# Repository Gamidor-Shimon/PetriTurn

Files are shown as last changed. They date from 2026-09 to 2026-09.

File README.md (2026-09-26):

# PetriTurn — Gamidor

מכשיר לסיבוב צלחת פטרי בזמן זריעת חיידקים.
הרובוט מחזיק את הלופה, והמכשיר מסובב את הצלחת לפי תוכנית שנשמרה מראש בבקר.

```
Robot → petriturn.exe (Python) → USB → XIAO ESP32-C3 → TMC2209 → NEMA17 → Petri dish
                 ↑
   petriturn_gui (program editor) → writes programs into the controller's flash
```

הפרויקט בנוי משלושה חלקים:

1. **קושחה** לבקר — `firmware/PetriTurn/PetriTurn.ino`
2. **שורת פקודה לרובוט** — `host/petriturn.py` (לאחר בנייה: `petriturn.exe`)
3. **תוכנת ניהול (GUI)** — `host/petriturn_gui.py`, בעיצוב Gamidor

---

## תוכן עניינים

1. [מבנה התיקיות](#מבנה-התיקיות)
2. [חומרה](#חומרה)
3. [התקנה ראשונה](#התקנה-ראשונה)
4. [קובץ ההגדרות petriturn.ini](#קובץ-ההגדרות-petriturnini)
5. [תוכנת הניהול (GUI)](#תוכנת-הניהול-gui)
6. [שורת הפקודה לרובוט](#שורת-הפקודה-לרובוט)
7. [פרוטוקול התקשורת עם הבקר](#פרוטוקול-התקשורת-עם-הבקר)
8. [פתרון תקלות](#פתרון-תקלות)
9. [בניית חבילה ללקוח](#בניית-חבילה-ללקוח)
10. [התקנה אצל הלקוח](#התקנה-אצל-הלקוח)
11. [כללי בטיחות](#כללי-בטיחות)

---

## מבנה התיקיות

```
PetriTurn/
├── README.md                      this document
├── WIRING.md                      pin-by-pin wiring: controller, driver, motor, power
├── Motor_Driver_Design_Notes.md   design notes: motor, driver, decisions, risks
├── PetriTurn.bat                  development only: runs the GUI from source (.venv)
├── build.bat                      builds the installer: PetriTurn\PetriTurn-Setup-<version>.exe
├── installer/                     Inno Setup script + Gamidor wizard images
├── enclosure/                     3D-printed box: FreeCAD script, STL, STEP, previews
├── perfboard/                     controller board: layout + check, README generator, drawings
├── requirements.txt               Python packages
├── firmware/
│   └── PetriTurn/
│       └── PetriTurn.ino       controller firmware
└── host/
    ├── petriturn.ini                settings: port, baud rate, timeouts
    ├── petriturn.py                 robot command line
    ├── petriturn_gui.py             control GUI
    ├── petriturn_link.py            shared code: serial link, programs, settings
    ├── petriturn_log.py             audit log (logs folder, 5 MB parts, never deleted)
    ├── theme.py                   Gamidor design tokens (gamidor-ui-design skill)
    └── assets/                    logo and icon
```

---

## חומרה

הפירוט המלא, רגל אחר רגל, עם שרטוטים ובדיקות: **[WIRING.md](WIRING.md)**.
הקופסה המודפסת (130 × 96, עם פאנל חיבורים), חלקים, הדפסה והרכבה: **[enclosure/README.md](enclosure/README.md)**.
לוח ההלחמה, סידור רכיבים וחיבורים: **[perfboard/README.md](perfboard/README.md)**.

### רכיבים

| רכיב | דגם / ערך |
|---|---|
| בקר | Seeed XIAO ESP32-C3 |
| דרייבר | TMC2209 (לוח V985), חיישת זרם `R110` = 0.11Ω |
| מנוע | LAM M1173040, NEMA17, ‏1.8°, ‏0.7A, ‏9.3Ω לסליל |
| ספק | 24V, לפחות 1.5A |
| קבל | 100µF / 35V אלקטרוליטי |
| נגדים | 1kΩ, ‏10kΩ |

### חיווט בקר ← דרייבר

| XIAO | GPIO | דרייבר TMC2209 | הערה |
|---|---|---|---|
| `3V3` | — | `VDD` (ימין, פין 7) | מתח לוגיקה |
| `GND` | — | `GND` (ימין, פין 8) | אדמה משותפת, חובה |
| `D1` | GPIO3 | `EN` (שמאל, פין 1) | + נגד **10kΩ מ-EN אל 3.3V** — המנוע כבוי בזמן עליית הבקר |
| `D2` | GPIO4 | `STEP` (שמאל, פין 7) | |
| `D3` | GPIO5 | `DIR` (שמאל, פין 8) | |
| `D4` | GPIO6 | `USART` (שמאל, פין 5) | **דרך נגד 1kΩ** |
| `D5` | GPIO7 | `USART` (שמאל, פין 5) | חוט ישיר |
| — | — | `MS1`, `MS2` | אל GND — כתובת דרייבר 0 |
| — | — | `PDN`, `CLK`, `DIAG`, `INDEX`, `VREF` | לא מחוברים |

- פינים `D0`, `D8`, `D9` של ה-XIAO הם פיני אתחול — **לא לחבר אליהם דבר**.
- `D6`/`D7` נשארים פנויים (הבקר מדפיס עליהם הודעות אתחול).
- **חוטים ליד שקע ה-USB-C** עלולים למנוע מהתקע להיכנס עד הסוף, והמחשב לא יזהה את הבקר. להרחיק אותם מהשקע.

### חיווט ספק ומנוע

| מ- | אל | הערה |
|---|---|---|
| ספק 24V (+) | `VM` (ימין, פין 1) | + רגל **+** (הארוכה) של קבל 100µF, צמוד לדרייבר |
| ספק 24V (−) | `GND` (ימין, פין 2) | + רגל **−** (הפס) של הקבל |
| מנוע שחור | `A2` (ימין, פין 3) | |
| מנוע ירוק | `A1` (ימין, פין 4) | |
| מנוע אדום | `B1` (ימין, פין 5) | |
| מנוע כחול | `B2` (ימין, פין 6) | |

בדיקה לפני חיבור המנוע: שחור–ירוק ≈ 9.3Ω, אדום–כחול ≈ 9.3Ω.

**סדר הדלקה:** USB קודם, 24V אחר כך. **כיבוי:** לשחרר את הצלחת, לכבות 24V, ואז USB.
כשאין 24V הדרייבר לא עונה (`DRV=0x00`) — זה תקין.

---

## התקנה ראשונה

### 1. קושחה (Arduino IDE)

1. **Boards Manager:** להתקין `esp32` by Espressif.
2. **Library Manager:** להתקין `TMCStepper` (teemuatlut) ו-`AccelStepper` (Mike McCauley).
3. לפתוח את `firmware/PetriTurn/PetriTurn.ino`.
4. **Tools:**
   - Board: `XIAO_ESP32C3`
   - USB CDC On Boot: **`Enabled`** — בלי זה אין תקשורת דרך ה-USB
   - Port: הפורט של הבקר
5. Upload.

אם הצריבה נכשלת: לנתק USB, להחזיק את כפתור **BOOT**, לחבר USB, לשחרר, ולצרוב שוב.

בדיקה ב-Serial Monitor (115200, סוף שורה `Newline`): לשלוח `STATUS`.
עם 24V מחובר צריך לחזור `DRV=0x21`.

### 2. תוכנה במחשב

צריך Python 3.11 ומעלה. מתיקיית הפרויקט:

```bash
python -m venv .venv
```
```bash
.venv\Scripts\python -m pip install -r requirements.txt
```

הסביבה `.venv` נשמרת בתוך תיקיית הפרויקט. ב-Python שמותקן מ-Microsoft Store,
התקנת PySide6 מחוץ לסביבה כזו נכשלת בגלל נתיבים ארוכים מדי.

### 3. הפעלה

- **GUI:** לחיצה כפולה על `PetriTurn.bat`
  (לא על `petriturn_gui.py` ישירות — אז הוא רץ עם ה-Python של המערכת, שאין בו PySide6).
- **שורת פקודה:**

```bash
.venv\Scripts\python host\petriturn.py status
```

---

## קובץ ההגדרות petriturn.ini

נמצא ב-`C:\ProgramData\PetriTurn\petriturn.ini` אחרי התקנה (בפיתוח: `host/petriturn.ini`).
**גם הרובוט וגם ה-GUI קוראים ממנו**, כך שהפורט מוגדר במקום אחד.
אם הקובץ חסר — הוא נוצר מחדש עם ברירות המחדל.

```ini
[connection]
port = COM6          ; USB port of the controller (Device Manager -> Ports)
baudrate = 115200    ; must match Serial.begin() in the firmware

[timeouts]
command = 3          ; seconds to wait for a quick command's reply
run_margin = 10      ; extra seconds on top of a program's estimated time

[gui]
poll_ms = 1000       ; GUI live-status refresh, milliseconds

[logs]
max_mb = 5           ; size of one log file; a new file every day and at this size
```

| מפתח | משמעות |
|---|---|
| `port` | פורט ה-USB של הבקר (מנהל ההתקנים ← יציאות COM ו-LPT) |
| `baudrate` | מהירות התקשורת. חייבת להתאים ל-`Serial.begin()` בקושחה |
| `command` | שניות להמתנה לתשובה על פקודה קצרה |
| `run_margin` | שניות נוספות מעבר לזמן המשוער של תוכנית, לפני שנחשב פסק זמן |
| `poll_ms` | קצב רענון המצב החי ב-GUI, במילישניות |
| `max_mb` | גודל מקסימלי של קובץ לוג אחד, במגה-בייט (ראו [לוגים](#לוגים)) |

---

## לוגים

**כל פעולה נרשמת, וקבצי הלוג לא נמחקים אף פעם.** התיקייה נוצרת לבד:
`C:\ProgramData\PetriTurn\logs` אחרי התקנה (בפיתוח: `host\logs`).

| קובץ | מי כותב |
|---|---|
| `2026-09-26_robot_001.log` | `petriturn.exe` — כל קריאה של הרובוט |
| `2026-09-26_gui_001.log` | `petriturn_gui.exe` — כל מה שמופיע בקונסולה של ה-GUI |

- **קובץ חדש כל יום**, ובנוסף כשהקובץ מגיע ל-`max_mb` (ברירת מחדל 5 MB) — ממשיכים ב-`_002`, `_003`...
- **מה נרשם על כל קריאה של הרובוט:** הפקודה המלאה, המשתמש והמחשב, הפורט, **כל שורה שנשלחה לבקר ושהתקבלה ממנו**,
  התוצאה, וקוד היציאה עם משך הזמן.
- כל שורה מתחילה בתאריך ושעה עד אלפית השנייה, ובמספר התהליך (`pid`) — כדי להבדיל בין קריאות.

```text
2026-09-26 14:03:12.340 [pid 4812] [start] petriturn 1.1 | command: petriturn rotate 0.25 10 cw | user lab1 | PC ROBOT-PC
2026-09-26 14:03:12.352 [pid 4812] [port] COM6 opened
2026-09-26 14:03:12.353 [pid 4812] [tx] INFO
2026-09-26 14:03:12.360 [pid 4812] [rx] OK SLOTS=20 MAX_STEPS=32 ...
2026-09-26 14:03:12.361 [pid 4812] [tx] ROT 90 10
2026-09-26 14:03:14.050 [pid 4812] [rx] OK
2026-09-26 14:03:14.051 [pid 4812] [result] OK
2026-09-26 14:03:14.052 [pid 4812] [exit] code 0 after 1.71 s
```

- **אם אי אפשר לכתוב לוג** (אין הרשאה, דיסק מלא): הרובוט מקבל אזהרה `WARN` ב-stderr (הפקודה עצמה מתבצעת),
  וה-GUI מציג בקונסולה באדום `LOG NOT SAVED`.
- **נפח:** קריאה של הרובוט היא כ-0.5 KB. 1,000 קריאות ביום ≈ 0.5 MB ביום ≈ 200 MB בשנה.
  מומלץ לגבות את התיקייה `logs` יחד עם שאר נתוני המעבדה.

- **חיבור מוצלח ב-GUI לפורט אחר כותב את הפורט החדש לקובץ** — הרובוט ישתמש בו אוטומטית.
- `--port` בשורת הפקודה עוקף את הקובץ לקריאה אחת בלבד.
- שינוי ידני: לערוך, לשמור, ולהפעיל את התוכנה מחדש.
- ערך לא תקין (למשל `baudrate = fast`) — התוכנה מודיעה על כך במפורש.

---

## תוכנת הניהול (GUI)

### עמודים

| עמוד | מה יש בו |
|---|---|
| **Programs** | 20 תאי תוכניות בבקר, עורך צעדים, שמירה והרצה |
| **Manual control** | החזקה / שחרור של הצלחת, סיבוב ידני, **הדגמה (demo)**, מצב חי, מקרא ערכים |
| **Info** | גרסה, מחבר, ופקודות הרובוט |

בשורה העליונה, תמיד גלויים: פורט, Connect, מצב חיבור, מצב דרייבר (`DRIVER OK` / `NO DRIVER`),
מצב מנוע (`HELD` / `FREE`), פעילות (`IDLE` / `RUNNING`) וכפתור **STOP**.
בתחתית — קונסולה עם כל פקודה ותשובה, שנשמרת גם בתיקיית `logs` (ראו [לוגים](#לוגים)).

### הדגמה (demo)

בעמוד **Manual control**, בכרטיס **demo**:

- **Start demo** — לולאה של 14 סיבובים, עם ונגד כיוון השעון, ב-5 עד 120 RPM
  (כ-39 שניות לסבב). כל סבב מסתיים בנקודה שבה התחיל. חוזר על עצמו עד שעוצרים.
- **Stop demo** — עוצר מיד, גם באמצע סיבוב. גם **STOP** בשורה העליונה עוצר את ההדגמה.
- תוך כדי מוצג הסבב, הצעד והסיבוב הנוכחי. שאר כפתורי התנועה נעולים.
- ההדגמה רצה מה-GUI ולא נשמרת בבקר — היא לא תופסת תא תוכנית.

### יצירת תוכנית

1. **Connect** לפורט של הבקר.
2. לבחור תא ברשימה משמאל (1–20).
3. **Name** — שם התוכנית (עד 24 בייטים; בעברית כ-12 אותיות; בלי `| , =`).
4. להוסיף צעדים עם **Add**:

| צעד | פרמטרים | מה קורה |
|---|---|---|
| **Rotate** | Turns, RPM | סיבוב. מספר שלילי = כיוון הפוך. אפשר שבר (0.25 = רבע סיבוב) |
| **Wait** | שניות | המתנה. הצלחת נשארת במצבה (מוחזקת או חופשית) |
| **Hold dish** | — | המנוע מחזיק — הצלחת נעולה |
| **Release dish** | — | המנוע משוחרר — הצלחת מסתובבת ביד |

5. **Save to controller** — נשמר בזיכרון הבקר, נשאר גם אחרי כיבוי.
6. **Run on controller** — הרצת בדיקה.

- **סיבוב תמיד רץ כשהמנוע מחזיק**, גם אחרי צעד Release.
  צעד אחרון **Hold dish** משאיר את הצלחת נעולה; **Release dish** — משחרר.
- Replace / Remove / ▲ ▼ — עריכת הצעד המסומן בטבלה.
- כפתור שלא יכול לעבוד כרגע — מושבת, ומתחתיו כתוב למה (למשל: אין 24V).
- הזמן המשוער של כל צעד ושל כל התוכנית מוצג בטבלה.

### מגבלות

| | מינימום | מקסימום |
|---|---|---|
| מהירות | 0.1 RPM | 120 RPM |
| סיבוב בצעד אחד | — | 100 סיבובים |
| המתנה בצעד אחד | — | 600 שניות |
| צעדים בתוכנית | 1 | 32 |
| תוכניות | — | 20 |
| תאוצה | קבועה: 1 סיבוב/שנייה² | |

**רק תוכנה אחת יכולה להחזיק את הפורט.** לפני שהרובוט עובד — **Disconnect** או לסגור את ה-GUI.
גם ה-Serial Monitor של Arduino תופס את הפורט.

---

## שורת הפקודה לרובוט

יש שתי דרכים לעבוד עם הרובוט:

**1. תוכנית שמורה** — הוגדרה מראש ב-GUI:

```bash
petriturn.exe run 3
```

**2. פקודות ישירות, בלי תוכנית** — הרובוט שולט בכל שלב בעצמו. למשל:

```bash
petriturn.exe hold
```
```bash
petriturn.exe rotate 2 30 cw
```
```bash
petriturn.exe rotate 0.5 10 ccw
```
```bash
petriturn.exe release
```

(נועלים את הצלחת, ממקמים את הלופה, מסובבים 2 סיבובים עם כיוון השעון ב-30 RPM,
חצי סיבוב נגד כיוון השעון ב-10 RPM, ומשחררים.)

| פקודה | מה היא עושה |
|---|---|
| `petriturn run <slot>` | מריץ תוכנית שמורה. **חוסם עד סוף התוכנית**, ואז יוצא |
| `petriturn rotate <turns> <rpm> cw` | סיבוב **עם** כיוון השעון. חוסם עד סוף הסיבוב |
| `petriturn rotate <turns> <rpm> ccw` | סיבוב **נגד** כיוון השעון. חוסם עד סוף הסיבוב |
| `petriturn hold` | נועל את הצלחת (המנוע מחזיק) |
| `petriturn release` | משחרר את הצלחת (מסתובבת ביד) |
| `petriturn stop` | עוצר תנועה (האטה ועצירה) |
| `petriturn status` | מצב הבקר (ראו [STATUS](#שדות-status)) |
| `petriturn list` | רשימת התוכניות השמורות |
| `petriturn ping` | בדיקת חיבור |
| `petriturn ports` | הפורטים הזמינים במחשב |

- `<turns>` — מספר סיבובים, חיובי. אפשר שבר: `0.25` = רבע סיבוב. עד 100.
- `<rpm>` — מהירות, 0.1 עד 120.
- `cw` / `ccw` — **כשמסתכלים על הצלחת מלמעלה.**
- סיבוב תמיד רץ כשהמנוע מחזיק; אחרי הסיבוב הצלחת **נשארת נעולה** עד `release`.
- `enable` / `disable` — שמות ישנים ל-`hold` / `release`, עדיין עובדים.
- `--port COM7` — פורט לקריאה זו בלבד. בלי זה — מ-`petriturn.ini`.

### קודי יציאה

| קוד | משמעות | מה הרובוט צריך לעשות |
|---|---|---|
| `0` | הצליח | להמשיך |
| `1` | פסק זמן, אין תשובה, הפורט תפוס, הדרייבר לא עונה, או STOP | לעצור ולהתריע |
| `2` | פקודה שגויה, ערך מחוץ לטווח, או תא ריק | לבדוק את הפקודה / התוכנית |

ההודעה (`OK` / `ERR <סיבה>`) נכתבת ל-stdout / stderr.

### תזמון

- הפעלה של `petriturn.exe` לוקחת כשנייה לפני שהפקודה נשלחת (נמדד: 0.85 שניות).
- `run` יוצא רק כשהתוכנית נגמרה. זמן ההמתנה המקסימלי = הזמן המשוער + `run_margin`.
- פתיחת הפורט **לא מאתחלת את הבקר** — הצלחת נשארת מוחזקת בין הרצות
  (נבדק: `UP` ממשיך לעלות בין קריאות).
- Ctrl+C בזמן `run` שולח STOP לבקר.

---

## פרוטוקול התקשורת עם הבקר

USB, ‏115200, כל שורה מסתיימת ב-`\n`. לכל פקודה — שורת תשובה אחת: `OK...` או `ERR <סיבה>`.
שורות שמתחילות ב-`#` הן הודעות מידע (למשל בעליית הבקר).

| פקודה | תשובה | הערה |
|---|---|---|
| `PING` | `OK PONG` | |
| `INFO` | `OK SLOTS=20 MAX_STEPS=32 MIN_RPM=0.1 MAX_RPM=120 MAX_DEG=36000 MAX_WAIT_MS=600000 ACCEL=1` | מגבלות הבקר |
| `STATUS` | `OK EN=.. BUSY=.. STEP=i/n POS=.. DRV=0x.. CUR=.. UP=.. URX=..` | |
| `DIAG` | `OK A0=12/0x21 ... IOIN=.. GSTAT=.. DRV_STATUS=..` | אבחון התקשורת עם הדרייבר |
| `EN` / `DIS` | `OK` | החזקה / שחרור |
| `ZERO` | `OK` | המיקום הנוכחי = 0° |
| `ROT <deg> <rpm>` | `OK` בסוף התנועה | |
| `RUN <slot>` | `OK` בסוף התוכנית | |
| `STOP` | `OK` כשהבקר פנוי | באמצע תנועה: אין תשובה משלו — הפקודה הרצה עונה `ERR STOPPED` |
| `PLIST` | `OK 1=Streak A,3=Quadrants` | |
| `PGET <slot>` | `OK <program>` | |
| `PSET <slot> <program>` | `OK` | |
| `PDEL <slot>` | `OK` | |

### פורמט תוכנית

```
<name>|<step>|<step>|...

ROT <deg> <rpm>    rotate (negative = other direction)
WAIT <ms>          wait
HOLD               hold the dish (motor energised)
RELEASE            release the dish (motor free)
```

דוגמה:

```
PSET 1 Streak A|HOLD|ROT 90 20|WAIT 1500|ROT 90 20|WAIT 1500|ROT -180 10|RELEASE
```

### שדות STATUS

| שדה | משמעות |
|---|---|
| `EN` | 1 = המנוע מחזיק, 0 = משוחרר |
| `BUSY` | 1 = תנועה או תוכנית רצה |
| `STEP` | הצעד הנוכחי בתוכנית / מספר הצעדים |
| `POS` | זווית במעלות מאז הדלקה או `ZERO` |
| `DRV` | `0x21` = הדרייבר עונה; `0x00` = לא עונה (בדרך כלל אין 24V) |
| `CUR` | זרם המנוע שנקבע בתוכנה, mA (≈560) |
| `UP` | שניות מאז הדלקת הבקר. **ירידה = הבקר אותחל** |
| `URX` | כמה פעמים ערוץ התקשורת לדרייבר נתקע והופעל מחדש אוטומטית. צריך להישאר 0 |

### קודי שגיאה

| קוד | משמעות |
|---|---|
| `DRIVER` | הדרייבר לא עונה — המנוע לא הוזז |
| `BUSY` | תנועה אחרת רצה |
| `STOPPED` | נעצר ב-STOP |
| `EMPTY_SLOT` | אין תוכנית בתא |
| `BAD_SLOT` | מספר תא לא בין 1 ל-20 |
| `BAD_ARGS`, `BAD_STEP` | צעד לא תקין |
| `BAD_NAME` | שם ריק, ארוך מ-24 בייטים, או עם `, =` |
| `NO_STEPS`, `TOO_MANY_STEPS` | 0 צעדים / יותר מ-32 |
| `DEG_RANGE`, `RPM_RANGE`, `WAIT_RANGE` | ערך מחוץ לטווח |
| `UNKNOWN_CMD` | פקודה לא מוכרת |
| `LINE_TOO_LONG` | שורה ארוכה מ-1024 תווים |
| `FLASH` | כתיבה לזיכרון נכשלה |

---

## פתרון תקלות

| תסמין | סיבה אפשרית | מה עושים |
|---|---|---|
| `DRV=0x00`, ‏`NO DRIVER` | אין 24V על הדרייבר | למדוד 24V בין `VM` ל-`GND` של הדרייבר |
| `DIAG` מחזיר `A0=0` בכל הכתובות | אין 24V, או ערוץ התקשורת תקוע | לבדוק 24V; אם קיים — כפתור `RST` ב-XIAO |
| `DIAG` מחזיר `A0=4` בכל הכתובות | החוטים תקינים אבל הדרייבר לא עונה | לבדוק `MS1`/`MS2` ל-GND; לנסות את פין `PDN` במקום `USART` |
| `URX` עולה מעל 0 | ערוץ התקשורת נתקע והבקר תיקן אותו | המנוע ממשיך לעבוד; לרשום מתי זה קרה |
| הפורט תפוס (`Access is denied`) | ה-GUI, ה-Serial Monitor או petriturn.exe אחר מחזיק אותו | לסגור אותם |
| המחשב לא מזהה את הבקר על המטריצה | חוט ליד שקע ה-USB-C חוסם את התקע | להרחיק חוטים מהשקע |
| המנוע רועד ולא מסתובב | זוגות הסלילים מעורבבים | 24V כבוי, למדוד A1–A2 ≈ 9.3Ω ו-B1–B2 ≈ 9.3Ω |
| הצלחת מסתובבת לכיוון ההפוך | — | `INVERT_DIR = true` בקושחה, בלי לגעת בחוטים |
| לחיצה כפולה על `petriturn_gui.py` לא פותחת כלום | רץ עם Python של המערכת, בלי PySide6 | להשתמש ב-`PetriTurn.bat` |
| הצריבה נכשלת | הבקר לא נכנס למצב צריבה | להחזיק BOOT בזמן חיבור ה-USB |

---

## בניית קובץ ההתקנה

מתיקיית הפרויקט (צריך את `.venv` מההתקנה הראשונה, ואת [Inno Setup 6](https://jrsoftware.org/isinfo.php)):

```bash
build.bat
```

התוצאה: **`PetriTurn\PetriTurn-Setup-1.1.exe`** — קובץ אחד, שמתקין הכל.
(`PetriTurn.bat` שבתיקיית הפרויקט הוא רק לפיתוח — מריץ את קוד המקור. ללקוח הוא לא מגיע.)

---

## התקנה אצל הלקוח

במחשב של הלקוח **לא צריך Python**, ולא צריך דרייבר ל-USB (Windows 10/11 מזהה את ה-XIAO לבד).

1. להריץ את `PetriTurn-Setup-1.1.exe` (מבקש הרשאת מנהל). באשף:
   - שפה: עברית או אנגלית;
   - תיקיית ההתקנה (ברירת מחדל `C:\Program Files\PetriTurn`);
   - **קיצור דרך בשולחן העבודה** — תיבת סימון.
2. לחבר את הבקר ב-USB. לחבר 24V.
3. להפעיל את **PetriTurn Control Center** (שולחן העבודה / תפריט התחל), לבחור את הפורט ו-**Connect**.
   הפורט נשמר ב-`petriturn.ini` — מעכשיו גם `petriturn.exe` משתמש בו.
4. **לבדוק כיוון:** בעמוד Manual control, סיבוב `0.25` (חיובי). הצלחת צריכה להסתובב
   **עם כיוון השעון כשמסתכלים עליה מלמעלה**. אם לא — לתקן `INVERT_DIR` בקושחה ולצרוב מחדש
   (לעשות את זה אצלנו, לפני המסירה).
5. להגדיר את התוכניות שהלקוח צריך, ולשמור.
6. **לסגור את ה-GUI** — הרובוט לא יכול לפתוח את הפורט כל עוד ה-GUI מחובר.
7. להגדיר ברובוט את הקריאות, עם הנתיב המלא. למשל:

```bash
"C:\Program Files\PetriTurn\petriturn.exe" run 1
```

   ולבדוק את קוד היציאה (`0` = הצליח).

**איפה מה:**

| מה | איפה |
|---|---|
| התוכנות, README, WIRING | תיקיית ההתקנה (`C:\Program Files\PetriTurn`) |
| `petriturn.ini` (הגדרות) | `C:\ProgramData\PetriTurn` — כל משתמש במחשב יכול לכתוב, כולל החשבון של הרובוט |
| הלוגים | `C:\ProgramData\PetriTurn\logs` |

בתפריט התחל ← PetriTurn יש קיצורים לתיקיית הלוגים ולתיקיית ההגדרות.
**הסרת התוכנה** (הגדרות ← אפליקציות) משאירה את `C:\ProgramData\PetriTurn` — ההגדרות והלוגים לא נמחקים.
**עדכון גרסה:** להריץ את קובץ ההתקנה החדש — הוא מחליף את התוכנות ומשאיר הגדרות ולוגים.

---

## כללי בטיחות

- **לעולם לא לחבר או לנתק את המנוע כשיש 24V.** זה שורף את הדרייבר.
- לשחרר את הצלחת (**Release dish**) לפני כיבוי ה-24V.
- הדרייבר מתחמם — צלע קירור ואוורור.
- אין חיישן אפס: המיקום יחסי, מאז ההדלקה או `ZERO`.
  פרטים ושיקולים — [Motor_Driver_Design_Notes.md](Motor_Driver_Design_Notes.md), סעיף 7.

---

Shimon Yeshayahu · Gamidor Diagnostics

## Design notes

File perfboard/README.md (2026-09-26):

# לוח ההלחמה — PetriTurn

הלוח: **לוח הלחמה בסגנון מטריצה, 89 × 52 מ"מ, בשלמותו.** 30 שורות, עמודות A–J.
בכל שורה **A–E מחוברים** ו-**F–J מחוברים**, ואין חיבור בין E ל-F (התעלה באמצע). פסי המתח שבצדדים לא בשימוש.

**כל המיקומים הם לפי המספרים והאותיות שמודפסים על הלוח.** במבט מלמעלה (הצד של הרכיבים): שורה 1 למעלה, A משמאל —
בדיוק כמו בציור `top.png`.
הסידור מוגדר ב-`layout.py` ונבדק אוטומטית: כל חיבור קיים, אין קצרים, רגליים שלא בשימוש לבד בפס שלהן.

| מלמעלה — רכיבים | מלמטה — חוטים (שורה 1 למעלה, **A מימין**) |
|---|---|
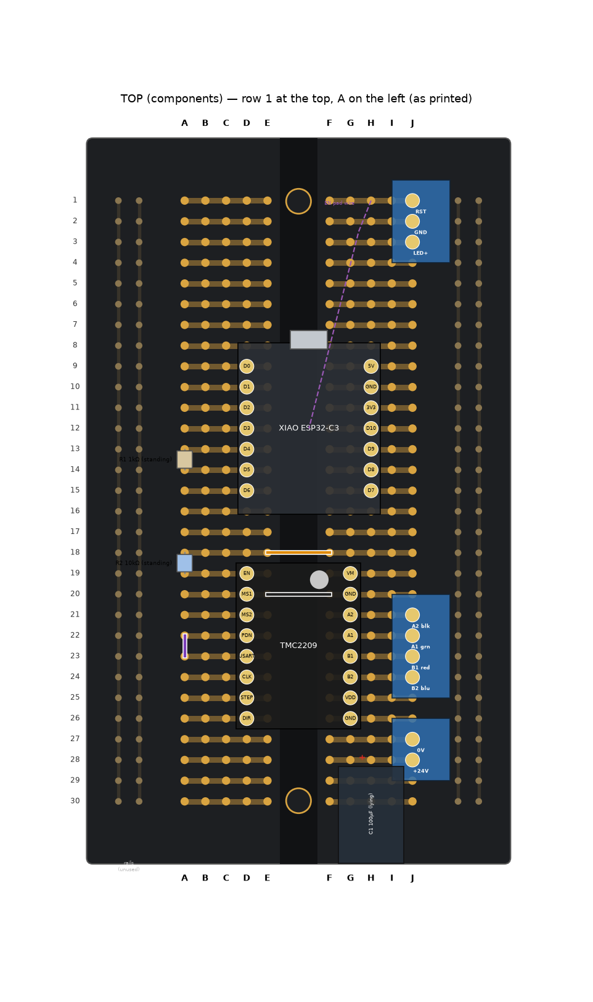
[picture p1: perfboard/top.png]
top
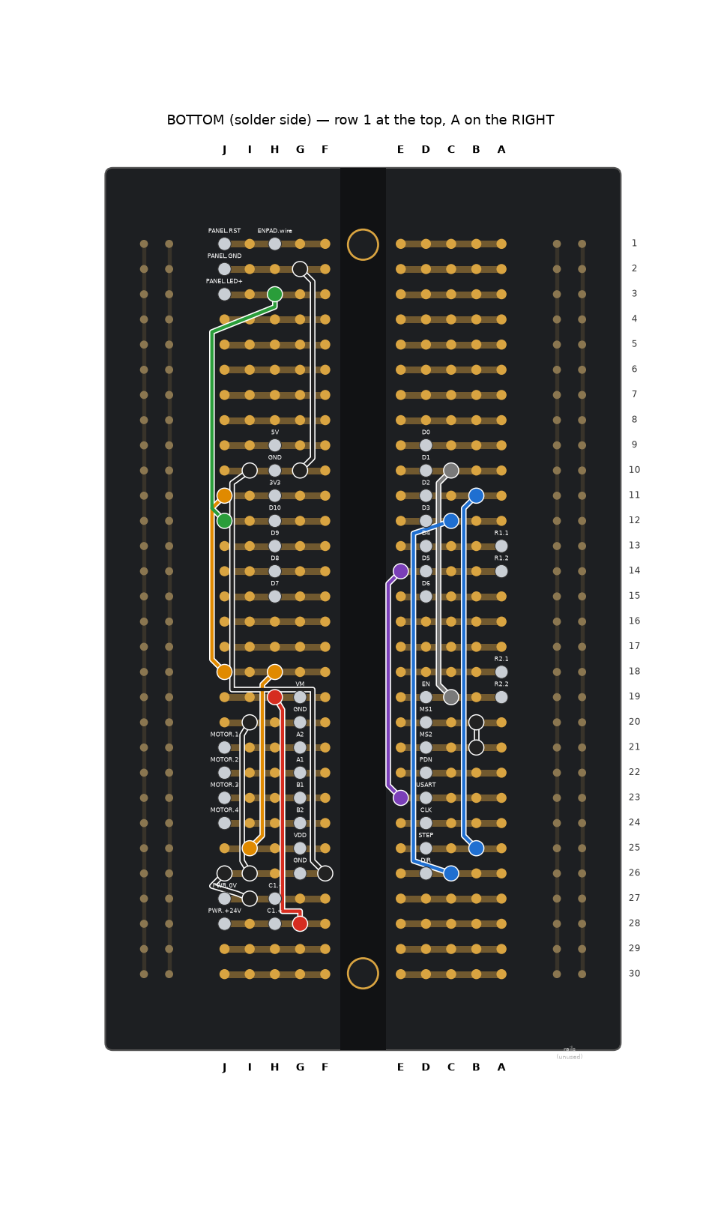
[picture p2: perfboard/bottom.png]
bottom
|  |  |

> **כמו שהרכיבים הונחו על הלוח (לפי התמונה):** XIAO בשורות 9–15, `D9` = D0, `H9` = 5V (VUSB).
> דרייבר בשורות 19–26, `D19` = EN, `G19` = VM.

---

## 1. הרכיבים

| רכיב | מיקום | הערה |
|---|---|---|
| **XIAO ESP32-C3** על 2 × 7 שקעים נקבה | עמודה `D` שורות 9–15: D0, D1, D2, D3, D4, D5, D6 · עמודה `H` שורות 9–15: 5V, GND, 3V3, D10, D9, D8, D7 | **הרכיבים למעלה, USB-C לכיוון שורה 1** |
| **TMC2209** על 2 × 8 שקעים נקבה | עמודה `D` שורות 19–26: EN, MS1, MS2, PDN, USART, CLK, STEP, DIR · עמודה `G` שורות 19–26: VM, GND, A2, A1, B1, B2, VDD, GND | **הפוטנציומטר לכיוון ה-XIAO** |
| **R1** 1kΩ | `A13` – `A14` | עומד |
| **R2** 10kΩ | `A18` – `A19` | עומד |
| **C1** 100µF / 35V | **+** `H28`, **−** `H27` | **שוכב** לאורך עמודה H, הגוף לכיוון שורה 30 (לא על בורג ההרכבה). **קוטביות!** |
| **מהדק מנוע** — 4 ברגים | `J21` A2, `J22` A1, `J23` B1, `J24` B2 | שחור, ירוק, אדום, כחול. יושב ישר על השורות של הדרייבר. פתחי החוטים החוצה |
| **מהדק מתח** — 2 ברגים | 0V `J27`, +24V `J28` | פתחי החוטים החוצה |
| **מהדק פאנל** — 3 ברגים | RST `J1`, GND `J2`, LED+ `J3` | פתחי החוטים החוצה |
| **חוט מ-EN** | משטח `EN` בגב ה-XIAO ← `H1` | חוט דק, ראו סעיף 4 |

**המהדקים בפסיעה 2.5 מ"מ:** כל רגל בשורה משלה, בשורות צמודות. כל המהדקים בעמודה J, פתחי החוטים החוצה מהלוח.

**בפאנל:**
- לד STATUS (**עם נגד מולחם עליו** — לכן אין נגד ללד על הלוח): הצד של הנגד / רגל ארוכה (+) ← **LED+**, רגל קצרה (−) ← **GND**.
- כפתור RESET: רגל אחת ← **RST**, רגל שנייה ← **GND** (שני חוטים באותו בורג GND).
- שקע המתח: + ← **+24V**, − ← **0V**.

---

## 2. רשימת כל החיבורים

לכל חיבור — כל החורים שחייבים להיות מחוברים זה לזה (דרך הפס או דרך חוט).
**שורה אחת בטבלה = חור אחד.** חורים באותה שורה ובאותו חצי (A–E או F–J) מחוברים כבר דרך הפס.

#### +24V (מתח המנוע)

| חור | מה מחובר |
|---|---|
| `G19` | דרייבר · VM |
| `H19` | קצה של חוט W12 |
| `G28` | קצה של חוט W12 |
| `H28` | C1 100µF · + (רגל ארוכה) |
| `J28` | מהדק מתח · +24V |

#### GND (אדמה)

| חור | מה מחובר |
|---|---|
| `G2` | קצה של חוט W14 |
| `J2` | מהדק פאנל · GND |
| `G10` | קצה של חוט W14 |
| `H10` | XIAO · GND |
| `I10` | קצה של חוט W11 |
| `B20` | קצה של חוט W9 |
| `D20` | דרייבר · MS1 |
| `E20` | קצה של חוט W8 |
| `F20` | קצה של חוט W8 |
| `G20` | דרייבר · GND (ליד VM) |
| `I20` | קצה של חוט W10 |
| `B21` | קצה של חוט W9 |
| `D21` | דרייבר · MS2 |
| `F26` | קצה של חוט W11 |
| `G26` | דרייבר · GND (האחרון) |
| `I26` | קצה של חוט W10 |
| `J26` | קצה של חוט W13 |
| `H27` | C1 100µF · − (פס לבן) |
| `I27` | קצה של חוט W13 |
| `J27` | מהדק מתח · 0V |

#### 3.3V

| חור | מה מחובר |
|---|---|
| `H11` | XIAO · 3V3 |
| `J11` | קצה של חוט W2 |
| `A18` | R2 10kΩ · רגל 1 |
| `E18` | קצה של חוט W1 |
| `F18` | קצה של חוט W1 |
| `H18` | קצה של חוט W3 |
| `J18` | קצה של חוט W2 |
| `G25` | דרייבר · VDD |
| `I25` | קצה של חוט W3 |

#### EN — הפעלת המנוע

| חור | מה מחובר |
|---|---|
| `C10` | קצה של חוט W4 |
| `D10` | XIAO · D1 |
| `A19` | R2 10kΩ · רגל 2 |
| `C19` | קצה של חוט W4 |
| `D19` | דרייבר · EN |

#### STEP

| חור | מה מחובר |
|---|---|
| `B11` | קצה של חוט W5 |
| `D11` | XIAO · D2 |
| `B25` | קצה של חוט W5 |
| `D25` | דרייבר · STEP |

#### DIR

| חור | מה מחובר |
|---|---|
| `C12` | קצה של חוט W6 |
| `D12` | XIAO · D3 |
| `C26` | קצה של חוט W6 |
| `D26` | דרייבר · DIR |

#### TX (D4, לפני R1)

| חור | מה מחובר |
|---|---|
| `A13` | R1 1kΩ · רגל 1 |
| `D13` | XIAO · D4 |

#### USART (תקשורת עם הדרייבר)

| חור | מה מחובר |
|---|---|
| `A14` | R1 1kΩ · רגל 2 |
| `D14` | XIAO · D5 |
| `E14` | קצה של חוט W7 |
| `A22` | קצה של חוט W16 |
| `D22` | דרייבר · PDN |
| `A23` | קצה של חוט W16 |
| `D23` | דרייבר · USART |
| `E23` | קצה של חוט W7 |

#### מנוע A2

| חור | מה מחובר |
|---|---|
| `G21` | דרייבר · A2 |
| `J21` | מהדק מנוע · 1 · A2 · חוט שחור |

#### מנוע A1

| חור | מה מחובר |
|---|---|
| `G22` | דרייבר · A1 |
| `J22` | מהדק מנוע · 2 · A1 · חוט ירוק |

#### מנוע B1

| חור | מה מחובר |
|---|---|
| `G23` | דרייבר · B1 |
| `J23` | מהדק מנוע · 3 · B1 · חוט אדום |

#### מנוע B2

| חור | מה מחובר |
|---|---|
| `G24` | דרייבר · B2 |
| `J24` | מהדק מנוע · 4 · B2 · חוט כחול |

#### לד (D10)

| חור | מה מחובר |
|---|---|
| `H3` | קצה של חוט W15 |
| `J3` | מהדק פאנל · LED+ |
| `H12` | XIAO · D10 |
| `J12` | קצה של חוט W15 |

#### RESET

| חור | מה מחובר |
|---|---|
| `H1` | חוט דק ממשטח EN בגב ה-XIAO · קצה |
| `J1` | מהדק פאנל · RST |

**רגליים שלא מחוברות לשום דבר** (לבד בפס שלהן): `D24` CLK, `D9` D0, `D15` D6, `H9` 5V, `H13` D9, `H14` D8, `H15` D7

---

## 3. חוטים

| חוט | מה | מ- | אל | צד | צבע |
|---|---|---|---|---|---|
| W1 | פס 3.3V — מחבר את שני חצאי שורה 18 | `E18` | `F18` | למעלה (קצר) | כתום |
| W2 | 3V3 של ה-XIAO ← פס 3.3V | `J11` | `J18` | למטה | כתום |
| W3 | פס 3.3V ← VDD של הדרייבר | `H18` | `I25` | למטה | כתום |
| W4 | D1 ← EN | `C10` | `C19` | למטה | אפור |
| W5 | D2 ← STEP | `B11` | `B25` | למטה | כחול |
| W6 | D3 ← DIR | `C12` | `C26` | למטה | כחול |
| W7 | D5 ← USART | `E14` | `E23` | למטה | סגול |
| W8 | MS1 ← GND (מעל התעלה) | `E20` | `F20` | למעלה (קצר) | שחור |
| W9 | MS2 ← MS1 / GND | `B20` | `B21` | למטה | שחור |
| W10 | GND ↔ GND של הדרייבר | `I20` | `I26` | למטה | שחור |
| W11 | GND של ה-XIAO ← GND | `I10` | `F26` | למטה | שחור |
| W12 | +24V: מהדק מתח ← VM | `H19` | `G28` | למטה | אדום |
| W13 | 0V: מהדק מתח ← GND | `J26` | `I27` | למטה | שחור |
| W14 | GND ← מהדק פאנל | `G10` | `G2` | למטה | שחור |
| W15 | לד + ← מהדק פאנל | `J12` | `H3` | למטה | ירוק |
| W16 | PDN ↔ USART — **התקשורת עוברת דרך PDN** | `A22` | `A23` | למעלה (קצר) | סגול |

- W1, W8, W16 **מעל הלוח**, קצרים (לפני שמכניסים את הדרייבר). כל השאר **מתחת ללוח** — לפי `bottom.png` (שם A מימין).
- חוטים מבודדים בלבד. כל קצה מולחם רק לחור שלו.
- **חוטי המתח** (W12, W13): חוט עבה יותר, 0.35–0.5 מ"מ².
- הקצה `I27` (W13) נמצא ליד מהדק המתח — מלחימים אותו **מלמטה**.

---

## 4. חוט האיפוס — משטח EN בגב ה-XIAO

כפתור RESET עושה **איפוס אמיתי**: מחבר את EN של ה-XIAO ל-GND.
EN הוא **משטח קטן בגב ה-XIAO** (מסומן `EN`), לא רגל.

1. להלחים חוט דק (wire-wrap) למשטח `EN` — מלחם נקי, נגיעה קצרה.
2. להעביר אותו מתחת ל-XIAO, בין שתי שורות השקעים, אל `H1`, ולהלחים שם.
3. מ-`H1` הפס מגיע לבורג **RST** במהדק הפאנל.
4. **בהחלפת XIAO** — להעביר את החוט ל-XIAO החדש.

---

## 5. בדיקה במולטימטר — בלי XIAO, בלי דרייבר, בלי מתח

מודדים על **חורים פנויים** באותם פסים.

| בין | צריך | מה זה בודק |
|---|---|---|
| `F28` ↔ `F27` | **אין צפצוף** | **אין קצר בין 24V ל-GND** |
| `F28` ↔ `F11` | **אין צפצוף** | **24V לא מגיע ל-3.3V** |
| `F28` ↔ `F19` | צפצוף | מהדק המתח מגיע ל-VM |
| `F27` ↔ `F10` | צפצוף | GND של הספק = GND של הבקר |
| `F27` ↔ `H26` | צפצוף | GND של הלוגיקה בדרייבר |
| `F27` ↔ `C20` | צפצוף | MS1 ל-GND |
| `F27` ↔ `E21` | צפצוף | MS2 ל-GND |
| `F27` ↔ `F2` | צפצוף | GND במהדק הפאנל |
| `F11` ↔ `F25` | צפצוף | 3.3V מגיע ל-VDD |
| `F11` ↔ `E19` | ≈10kΩ | R2: EN ← 3.3V |
| `E10` ↔ `E19` | צפצוף | D1 → EN |
| `E11` ↔ `E25` | צפצוף | D2 → STEP |
| `E12` ↔ `E26` | צפצוף | D3 → DIR |
| `C14` ↔ `C23` | צפצוף | D5 → USART |
| `E13` ↔ `C23` | ≈1kΩ | D4 → R1 → USART |
| `F12` ↔ `F3` | צפצוף | D10 → מהדק הלד |
| `F21` ↔ `F22` | **אין צפצוף** | אין קצר בין חוטי המנוע |
| `F22` ↔ `F23` | **אין צפצוף** |  |
| `F23` ↔ `F24` | **אין צפצוף** |  |
| `F1` ↔ `F2` | **אין צפצוף** | RESET לא מקוצר ל-GND |
| `E22` ↔ `C23` | צפצוף | PDN מחובר לקו התקשורת (גשר) |
| `E24` ↔ `E25` | **אין צפצוף** | CLK לבד |

**אחרי שה-XIAO והדרייבר בשקעים** (עדיין בלי מתח):
- המתכת של שקע ה-USB-C ↔ `F10` — **צפצוף**.
- `H26` ↔ `F27` — **צפצוף**.

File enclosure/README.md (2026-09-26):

# קופסה מודפסת — PetriTurn

קופסה של **130 × 96 × 57 מ"מ**. המנוע בפנים, הציר יוצא למעלה, ועליו קן שמחזיק צלחת פטרי 90 מ"מ.
בצד שמאל — לוח ההלחמה המלא (89 × 52, בלי חיתוך). בצד ימין — **פאנל חיבורים**: USB, ‏24V, לד STATUS וכפתור RESET.

> הקופסה **רחבה מטביעת SBS** (127.76 × 85.48) כדי שהלוח ייכנס בלי לחתוך אותו.
> היא לא נכנסת לעמדת צלחת רגילה על משטח הרובוט — צריך מקום ייעודי.

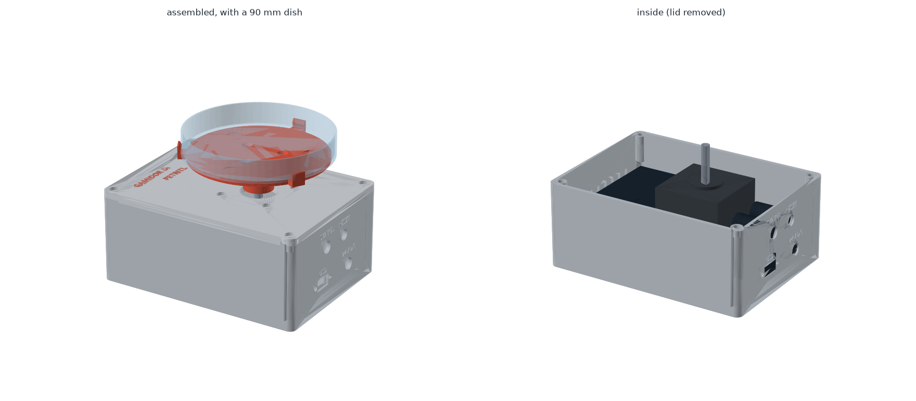
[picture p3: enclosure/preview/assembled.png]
assembled


| | |
|---|---|
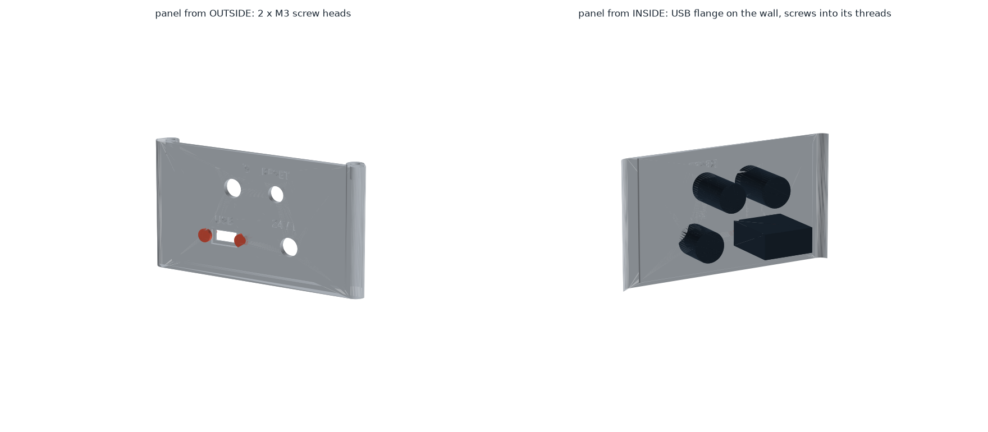
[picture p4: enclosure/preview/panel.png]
panel
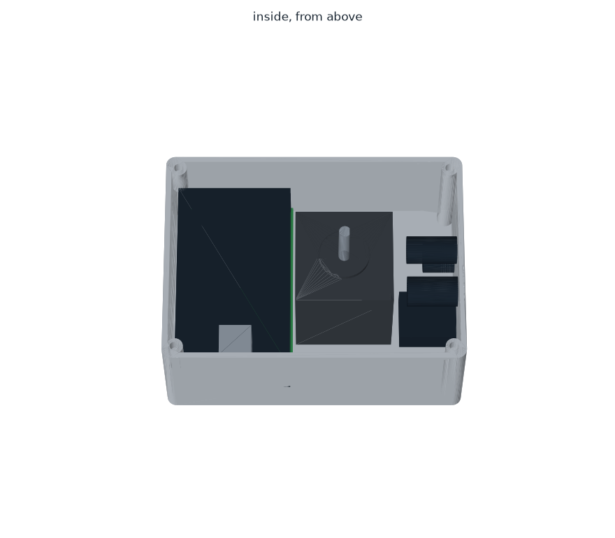
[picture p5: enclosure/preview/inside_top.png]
inside
|  |  |

---

## החלקים

| קובץ | חלק | כיוון הדפסה |
|---|---|---|
| `stl/base.stl` | גוף הקופסה: דפנות, עמודי ברגים, מעמדים ללוח, פאנל חיבורים (ימין), חריצי אוורור (שמאל) | כמו שהוא, הפתח למעלה |
| `stl/lid.stl` | מכסה. המנוע תלוי מתחתיו | **הפוך** — הצד העליון על המשטח (כבר מסובב בקובץ) |
| `stl/lid_text.stl` | הכיתוב של המכסה, כגוף נפרד | יחד עם `lid.stl`, בצבע שני |
| `stl/hub.stl` | תופס את ציר המנוע | הפלנג' הרחב על המשטח (כבר מסובב בקובץ) |
| `stl/plate.stl` | הקן: הצלחת יושבת עליו, 3 תפסים מחזיקים אותה | כמו שהוא, התפסים למעלה |

הקבצים ב-`stl/` כבר מסובבים ומונחים על המשטח. ב-`step/` — אותם חלקים במצב מורכב, לעריכה ב-CAD.
**כל החלקים מודפסים בלי תמיכות.** שני עמודי הברגים שמעל הלוח "תלויים" מלמעלה ומסתיימים בחרוט של 45° —
גם הם בלי תמיכות.

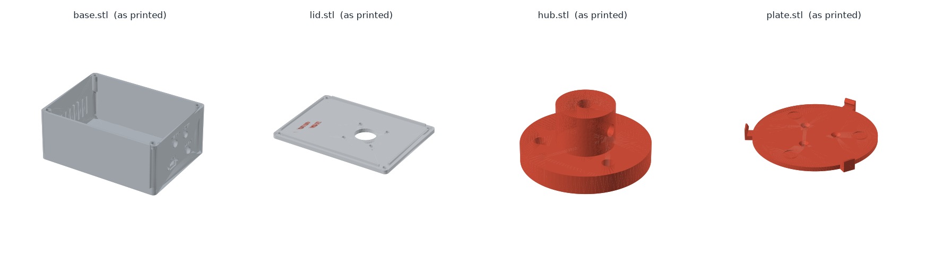
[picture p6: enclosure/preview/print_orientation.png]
print orientation


### הגדרות הדפסה (Bambu Lab, PETG)

| חלק | שכבה | דפנות | מילוי | תמיכות |
|---|---|---|---|---|
| base | 0.2 מ"מ | 3 | 15% gyroid | לא |
| lid + lid_text | 0.2 מ"מ | 3 | 15% gyroid | לא |
| hub | 0.2 מ"מ | 5 | 50% gyroid | לא |
| plate | 0.2 מ"מ | 4 | 30% gyroid | לא |

**כיתוב בשני צבעים (AMS):** לגרור את `lid.stl` ואת `lid_text.stl` **ביחד** ל-Bambu Studio,
ולענות **Yes** לשאלה אם לטעון כחלקים של אובייקט אחד. לבחור ל-`lid_text` פילמנט כתום.
בלי AMS — להדפיס רק את `lid.stl`; הכיתוב יהיה חרוט.

---

## פאנל החיבורים (הדופן הימנית)

```
        STATUS          RESET
        ( 8 )           ( 7 )

   USB                  24V DC
 o [==]  o              ( 8 )
```

| חיבור | חור | הרכבה |
|---|---|---|
| **USB** | חלון 10 × 4.5 מ"מ + שקע רדוד 12.4 × 7 לראש התקע, 2 חורי מעבר M3 (3.4) במרחק 17 | שקע ה-USB והפלנץ שלו **צמודים לדופן מבפנים**. 2 ברגי M3 נכנסים **מבחוץ**, עוברים דרך הדופן ומתברגים לחורי ההברגה שבפלנץ |
| **24V DC** | Ø8 | שקע 5.5 × 2.1 לפאנל (DC-022B), אום מבפנים |
| **STATUS** | Ø8 | בית ללד 5 מ"מ |
| **RESET** | Ø7 | לחצן רגעי |

panel outside / inside

בגלל שהשקע יושב מאחורי הדופן, ראש הפלסטיק של תקע ה-USB נכנס לשקע הרדוד, והדופן מול השקע היא רק 0.8 מ"מ —
כך התקע נכנס (כמעט) עד הסוף.

---

## חומרה לקנייה

| פריט | כמות | איפה |
|---|---|---|
| תותבת הברגה M3 לחימום (M3 × 5.7, קוטר חיצוני 4.6) | 8 | 4 בעמודי הבסיס, 3 בפלנג' של ה-hub, 1 בצד ה-hub |
| בורג M3 × 8 ראש כפתור (button head) | 4 | מכסה ← בסיס |
| בורג M3 × 6 ראש כפתור | 4 | מנוע ← מכסה |
| בורג M3 × 8 ראש שקוע (flat head) | 3 | קן ← hub |
| בורג ללא ראש (grub / set screw) M3 × 8 | 1 | hub ← ציר המנוע |
| בורג M3 × 8 | 2 | לוח ← מעמדים |
| כבל USB-C מאריך לפאנל (עם 2 ברגי M3) | 1 | פאנל |
| **מתאם USB-C 90°** (זכר-נקבה, L, זווית למעלה) | 1 | על ה-XIAO |
| שקע מתח לפאנל 5.5 × 2.1 (DC-022B, חור 8 מ"מ) | 1 | פאנל |
| לד 5 מ"מ + בית ללד 8 מ"מ | 1 | פאנל |
| לחצן רגעי (NO), חור 7 מ"מ | 1 | פאנל |
| לוח הלחמה בסגנון מטריצה 89 × 52 | 1 | [perfboard/README.md](../perfboard/README.md) |
| פס שקעים נקבה (female header) 2.54 | 2×7 + 2×8 | ל-XIAO ולדרייבר |
| מדבקות סיליקון נגד החלקה, Ø10 | 3 | בשקעים שעל הקן (לא חובה) |

---

## לפני ההדפסה — למדוד

המידות בראש `build_enclosure.py`, מסומנות `(MEASURE)`:

| פרמטר | מה למדוד | ברירת מחדל |
|---|---|---|
| `PB_MOUNT_DY` | מרחק בין מרכזי שני חורי ההרכבה של הלוח (במרכז הקצוות הקצרים) | 73.5 (נמדד) |
| `DISH_D` | קוטר חיצוני של תחתית הצלחת שהלקוח משתמש בה | 90.0 |
| `SHAFT_L` | אורך הציר מפני המנוע (לא מראש הבליטה העגולה) עד הקצה | 24.0 |
| `MOTOR_L` | אורך גוף המנוע | 48.0 |
| `DC_HOLE_D` | בתוך `PANEL`: קוטר ההברגה של שקע המתח | 8.0 |

כל המידות של הלוח ושל שקע ה-USB נמדדו — **כל החלקים מוכנים להדפסה.**

### עדכון והרצה

**כמקרו ב-FreeCAD** (מציג את הקופסה ומייצר את הקבצים):
FreeCAD ← File ← Open ← `enclosure/build_enclosure.py` ← Macro ← Execute macro (Ctrl+F6).

**בלי חלון**, מתיקיית הפרויקט:

```bash
"C:\Program Files\FreeCAD 1.1\bin\freecadcmd.exe" -c "exec(open(r'enclosure/build_enclosure.py', encoding='utf-8').read(), {'__file__': r'enclosure/build_enclosure.py'})"
```
```bash
.venv\Scripts\python enclosure\preview_enclosure.py
```

`build_report.txt` בודק התנגשויות בין החלקים לבין מודלים של המנוע, הלוח, מתאם ה-USB וחלקי הפאנל —
צריך להיות בו **אפס** שורות `COLLISION`.

---

## הרכבה

1. **תותבות:** עם מלחם (כ-230°C) — 4 בראשי עמודי הבסיס, 3 בפלנג' של ה-hub מהצד השטוח, 1 בחור הצדדי של ה-hub.
2. **פאנל:** כבל ה-USB (פלנץ מבפנים, 2 × M3 מבחוץ), שקע 24V, בית הלד, הכפתור.
3. **לוח:** 2 ברגי M3 בחורי ההרכבה, שורה 1 לכיוון הדופן האחורית, ועמודה J (המהדקים) לכיוון המנוע. מתאם 90° על ה-USB של ה-XIAO, והכבל אליו.
4. **חוטים:** 24V, לד וכפתור מהפאנל ללוח — לפי [perfboard/README.md](../perfboard/README.md).
5. **מנוע:** להבריג מתחת למכסה (4 × M3×6). **לחבר את מחבר המנוע ללוח כשאין 24V.**
6. **מכסה:** להניח על הבסיס (השוליים שמתחתיו נכנסים לדפנות), 4 × M3×8.
7. **hub:** להשחיל על הציר, הבורג הצדדי מול הצד השטוח של הציר, ולהדק. רווח של כ-2 מ"מ מהמכסה.
8. **קן:** להבריג ל-hub (3 × M3×8 ראש שקוע). מדבקות סיליקון בשקעים.
9. בדיקה: `petriturn.exe rotate 1 20 cw` — הקן מסתובב חופשי, בלי לשפשף במכסה.

---

## הצלחת והרובוט

- התפסים **נמוכים (5 מ"מ)** ותופסים את תחתית דופן הצלחת. **דופן הצלחת מעליהם פנויה מכל הצדדים**
  לאצבעות של הרובוט, בכל זווית שבה הקן עצר.
- **גובה תחתית הצלחת: 81.4 מ"מ** מעל משטח העבודה.
- **מרכז הצלחת לא במרכז הקופסה:** הוא 13 מ"מ ימינה (לכיוון הפאנל). לכייל את הרובוט למרכז הצלחת.
- **להוריד את הגובה:** לקצר את ציר המנוע ולעדכן `SHAFT_L` — כל מ"מ שמקצרים מוריד מ"מ. או מנוע NEMA17 שטוח.

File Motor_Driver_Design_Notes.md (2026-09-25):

# מסמך תכנון: מנוע צעד + דרייבר + בקר לסיבוב צלחת פטרי

תאריך: 24.09.2026

---

## 1. מטרת המערכת

המנוע מסובב צלחת פטרי בזמן זריעה. רובוט מחזיק את הלופה ושולט בתזמון.
כל פקודה נשלחת מהמחשב באמצעות קובץ הפעלה, ועוברת לבקר דרך חיבור טורי.

```
Robot → EXE (Python) → USB Serial → XIAO ESP32-C3 → TMC2209 → Motor → Petri dish
```

---

## 2. נתוני המנוע (ודאות גבוהה, מתוך דף נתונים)

| פרמטר | ערך |
|---|---|
| דגם | `LAM M1173040` |
| גודל | `NEMA17, L=48mm` |
| זווית צעד | `1.8° = 200 steps/rev` |
| זרם | `0.7 A rms` |
| התנגדות | `9.3 Ω` |
| השראות | `17.8 mH` |
| מומנט החזקה | `0.5 Nm` |
| חיווט | `4 wires, bipolar` |

**מסקנה:** ההשראות גבוהה. במהירות גבוהה המומנט יורד.
למהירות סיבוב של צלחת בזמן זריעה זו לא בעיה. ודאות בינונית-גבוהה.

---

## 3. חיווט מנוע ← דרייבר

החיווט המלא של המערכת, רגל אחר רגל: [WIRING.md](WIRING.md).

| צבע חוט | סליל | פין בדרייבר |
|---|---|---|
| שחור | סליל ראשון | `A2` |
| ירוק | סליל ראשון | `A1` |
| אדום | סליל שני | `B1` |
| כחול | סליל שני | `B2` |

- בדיקה לפני חיבור: מולטימטר בין שני חוטים של אותו סליל.

```
Black–Green ≈ 9.3Ω ,  Red–Blue ≈ 9.3Ω ,  Black–Red = open
```

- אם המנוע מסתובב הפוך: להחליף שני חוטים בתוך אותו זוג, או להפוך בתוכנה.
- **🔴 לעולם לא לחבר או לנתק את המנוע כשיש מתח. זה שורף את הדרייבר.**

---

## 4. כבל למנוע (החוטים חשופים)

- ארבעה גידים, שני זוגות שזורים. כל זוג הולך לסליל אחד.

```
22–24 AWG, 4-core, twisted pairs
Shielded if longer than ~50cm (shield → GND at driver side only)
```

- בצד הדרייבר: מחבר עם נעילה, כדי שהכבל לא ייפול בזמן עבודה.

```
JST-XH 4-pin  (or screw terminal)
```

- בצד המנוע: הלחמה ושרוול מתכווץ. לקבע את הכבל לקופסה כדי שלא יימשך.

---

## 5. חיווט דרייבר ← בקר וספק

בקר: **Seeed XIAO ESP32-C3**. פינים `D0`, `D8`, `D9` הם פיני אתחול (strapping) ונשארים ריקים.

| פין בדרייבר | מתחבר אל | הערה |
|---|---|---|
| `VM` | `24V (+)` | מתח מנוע |
| `GND` (ליד `VM`) | `24V (-)` | |
| `VDD` | `XIAO 3V3` | מתח לוגיקה |
| `GND` (ליד `VDD`) | `XIAO GND` | אדמה משותפת, חובה |
| `STEP` | `D2 (GPIO4)` | |
| `DIR` | `D3 (GPIO5)` | |
| `EN` | `D1 (GPIO3)` | נמוך = מנוע פעיל |
| `USART` (פין 5 משמאל) | `D5 (GPIO7, RX)` ישיר, `D4 (GPIO6, TX)` דרך נגד | תקשורת בחוט אחד. בלוח V985: `PDN` (פין 4) לא מחובר, אלא אם בדיקת רציפות הראתה שהוא מקוצר ל-`USART` |
| `MS1`, `MS2` | `GND` | כתובת 0 |
| `CLK`, `INDEX`, `DIAG` | לא מחובר | |

רכיבים נוספים:

```
100µF / 35V electrolytic capacitor across VM–GND, close to the driver
1kΩ resistor between XIAO D4 (TX) and USART
10kΩ pull-up from driver EN to 3.3V  → motor stays OFF while the controller boots
```

**סדר הדלקה:** קודם לוגיקה, אחר כך מתח מנוע. בכיבוי: הפוך.

---

## 6. הגדרת זרם

המלצה: לקבוע זרם בתוכנה דרך החיבור הטורי, ולא בפוטנציומטר.
על הלוח מסומן נגד חישה:

```
R110 = 0.110 Ω   (verify on your board)
```

ערכי הגדרה מומלצים:

```cpp
driver.begin();
driver.toff(4);
driver.rms_current(560);      // 80% of 0.7A → less heat
driver.microsteps(16);        // + internal 256 interpolation
driver.en_spreadCycle(false); // StealthChop: quiet + smooth at low speed
driver.pwm_autoscale(true);
```

בדיקת תקשורת: קריאה של גרסת השבב צריכה להחזיר

```
driver.version() == 0x21
```

---

## 7. חיישן נקודת אפס — החלטה

**החלטה: לא צריך חיישן.** ודאות בינונית-גבוהה.

הנימוק: הצלחת עגולה, וכל נקודה יכולה להיות התחלה של זריעה.
מספיק מיקום יחסי בתוך סשן אחד.

**התנאים שבהם ההחלטה נכונה:**

1. הבקר לא מתאפס באמצע סשן. ראה סעיף 8.
2. המנוע לא מאבד צעדים. אין משוב, ולכן אי אפשר לגלות איבוד צעדים.
3. אין צורך ביישור הצלחת ביחס לתווית או לברקוד.
4. אין צורך בזריעה מחולקת לרבעים שחוזרת לאותה נקודה בסשן אחר.

**אם אחד התנאים ישתנה בעתיד**, האפשרות המומלצת היא חיישן אופטי עם חריץ ודגל על הצלחת המסתובבת:

```
Optical slot sensor: TCST2103 / EE-SX670
```

לא מומלץ: זיהוי עצירה של השבב ללא חיישן. עם מנוע של השראה גבוהה ובמהירות נמוכה זה לא אמין.

```
StallGuard (DIAG pin) — not recommended here
```

---

## 8. 🔴 סיכון קריטי: איפוס הבקר בכל הרצה

בכל הרצה, קובץ ההפעלה פותח את הפורט הטורי. ברוב לוחות הפיתוח זה מאפס את הבקר.
תוצאה: המנוע משתחרר, והצלחת עלולה לזוז.

פתרון כפול:

1. בתוכנה: לכבות את שני קווי האיפוס לפני פתיחת הפורט.
2. ~~בחומרה: קבל בין פין האיפוס לאדמה.~~ **לא רלוונטי ל-XIAO ESP32-C3:** ה-USB מחובר ישירות לשבב, והאיפוס מה-USB נעשה בתוך השבב ולא דרך פין EN. ההגנה היא בתוכנה בלבד.
3. בדיקה: `STATUS` מחזיר `UP=<שניות מאז הדלקה>`. אם הערך קטן בין הרצות, הבקר התאפס.

```python
import serial
ser = serial.Serial()
ser.port = "COM5"
ser.baudrate = 115200
ser.dtr = False
ser.rts = False
ser.timeout = 30
ser.open()
```

```
Hardware: not applicable on XIAO ESP32-C3 (native USB, internal reset)
```

---

## 9. ממשק פקודות מול הרובוט

הנחה: הרובוט מריץ את קובץ ההפעלה ומחכה לסיום. התשובה על שאלה זו עדיין לא התקבלה.

דוגמאות שימוש:

```
petriturn.exe rotate 360 30     → rotate 360° at 30 RPM, wait until done
petriturn.exe enable
petriturn.exe disable
petriturn.exe status
```

כללים:

- קובץ ההפעלה חוסם עד סוף התנועה, ואז יוצא. הרובוט ממשיך רק אחרי זה.
- קוד יציאה: הצלחה = אפס, שגיאה = אחרת. הרובוט יכול לבדוק אותו.

```
exit 0 = OK ,  exit 1 = timeout / no reply ,  exit 2 = bad command
```

- פרוטוקול טקסט פשוט בין המחשב לבקר, עם תשובה לכל פקודה:

```
PC → "ROT 360 30\n"      ESP32 → "OK\n"  (after motion ends)  or  "ERR <reason>\n"
```

- זמן עלייה של קובץ הפעלה בודד: שנייה עד שלוש. לקחת בחשבון בתזמון הרובוט.

```
PyInstaller --onefile ≈ 1–3 s startup
```

---

## 10. מכניקה — נקודות לבדיקה

- הצלחת חייבת להיות מקובעת. הלופה לוחצת על האגר, והצלחת לא אמורה להחליק.
- מומנט המנוע גדול בהרבה ממה שנדרש לסיבוב צלחת. ודאות גבוהה.
- חיבור ישיר מהציר לצלחת, בלי תמסורת. במיקרו-צעדים יש מספיק רזולוציה:

```
200 × 16 = 3200 steps/rev → 0.1125° per step
```

- הדרייבר מתחמם. לשים את הצלעות הקירור שהגיעו איתו, ולהשאיר פתח אוורור בקופסה.

---

## 11. רשימת חלקים

| פריט | מפרט |
|---|---|
| ספק | `24V, ≥1.5A` |
| קבל | `100µF / 35V` |
| נגדים | `1kΩ`, `10kΩ` |
| בקר | `Seeed XIAO ESP32-C3` |
| כבל | `4-core 22–24 AWG, twisted pairs` |
| מחבר | `JST-XH 4-pin` |
| מחבר מתח | `DC barrel 5.5×2.1` |

---

## 12. שאלות פתוחות

1. מי מריץ את קובץ ההפעלה, ובאיזו תוכנה? זה משפיע על טיפול בשגיאות ובזמנים.
2. באיזו מהירות סיבוב הזריעה צריכה להיות, ובכמה סיבובים?
3. איך הצלחת מקובעת על ציר המנוע?
4. מה קורה אם הבקר לא עונה באמצע ריצה? מה הרובוט צריך לעשות?

---

## 13. שלבי המשך

1. בדיקת התנגדות סלילים במולטימטר.
2. חיווט על מטריצה, ובדיקת תקשורת עם הדרייבר.
3. קושחה בסיסית לבקר: קבלת פקודות וסיבוב.
4. סקריפט פייתון והמרה לקובץ הפעלה.
5. בדיקה: עשר הרצות ברצף. לוודא שאין איפוס ושאין תזוזה של הצלחת.

---

## 14. תוכניות שמורות בבקר (עדכון)

**החלטה:** מהירויות וסיבובים לא נקבעים מראש. כל לקוח מקבל תוכנית, שנבנית בממשק גרפי ונשמרת בזיכרון הקבוע של הבקר.
זה עונה על שאלה פתוחה 2.

```
GUI (petriturn_gui) → PSET → ESP32 flash (20 slots, up to 32 steps each)
Robot → petriturn.exe run <slot> → RUN <slot> → "OK" when the program ends
```

- צעד בתוכנית: סיבוב (סיבובים, מהירות), המתנה, החזקת צלחת (`HOLD`) או שחרור (`RELEASE`). מספר שלילי = כיוון הפוך.
- סיבוב תמיד רץ כשהמנוע מחזיק, גם אחרי צעד שחרור. `HOLD` / `RELEASE` בסוף התוכנית קובעים אם הצלחת נשארת נעולה.
- התוכניות נשמרות גם אחרי כיבוי.
- ה-GUI והרובוט לא יכולים להחזיק את הפורט באותו זמן. לסגור את ה-GUI לפני עבודה.
- הפרוטוקול המלא: בראש הקובץ `firmware/PetriTurn/PetriTurn.ino`.
- ה-GUI: `host/petriturn_gui.py`, PySide6, בעיצוב Gamidor (סקיל `gamidor-ui-design`). רץ מתוך הסביבה `.venv` שבתיקיית הפרויקט.

---

מקורות:

- [M11730xx datasheet](https://www.mechapro.de/pdf/M11730xx_DSUK.pdf)
- [LAM M1173040 product page](https://www.lamtechnologies.com/Product.aspx?lng=EN&idp=m1173040)

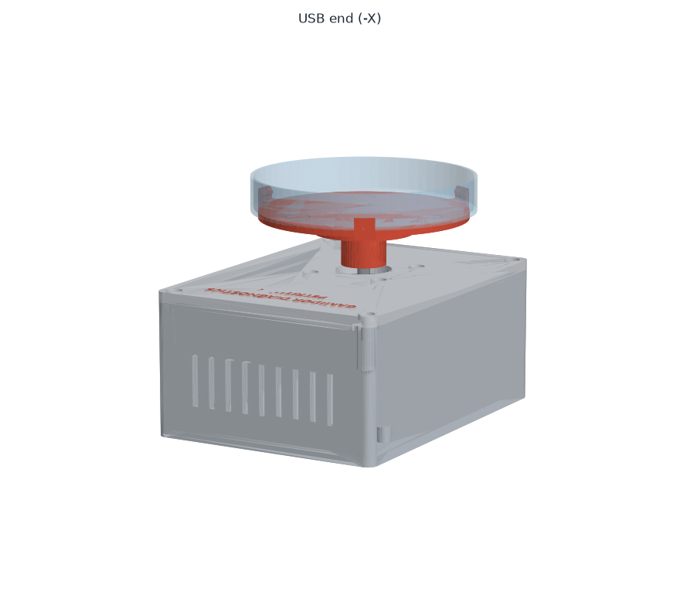
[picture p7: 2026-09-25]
enclosure/preview/usb_end.png

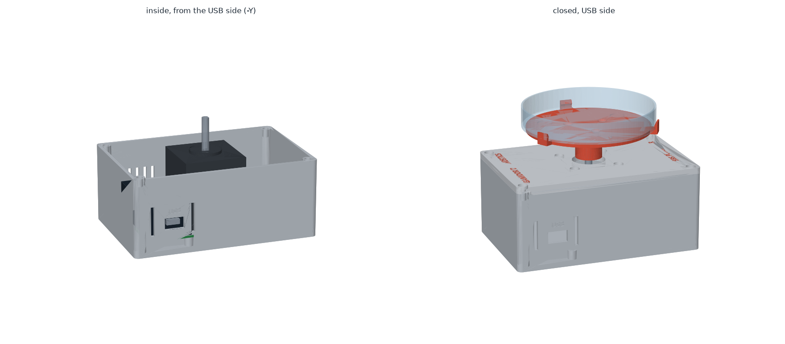
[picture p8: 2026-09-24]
enclosure/preview/usb_side.png

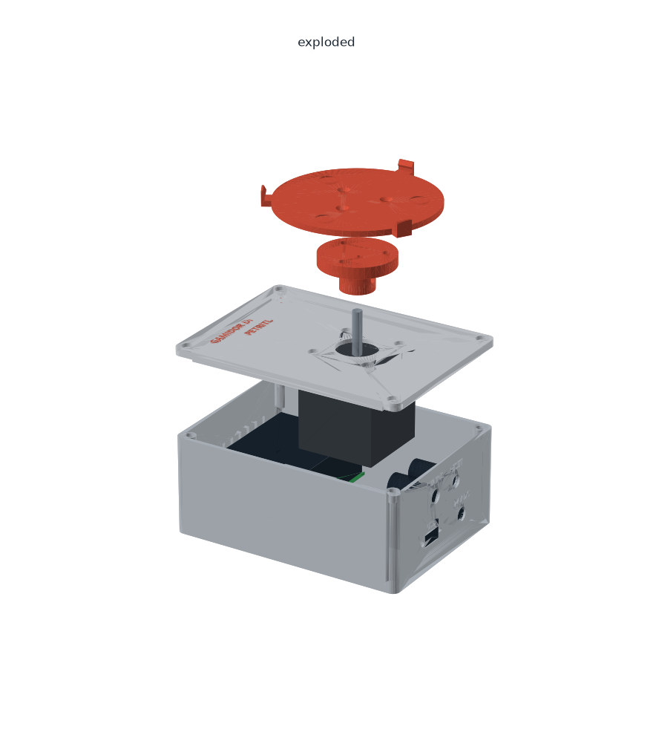
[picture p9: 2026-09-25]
enclosure/preview/exploded.png

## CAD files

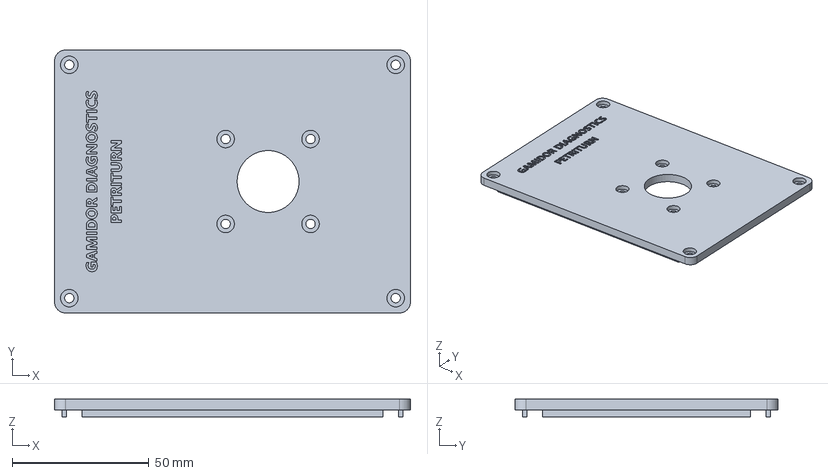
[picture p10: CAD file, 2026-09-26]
enclosure/step/lid.step
130.0 x 96.0 x 6.50 mm

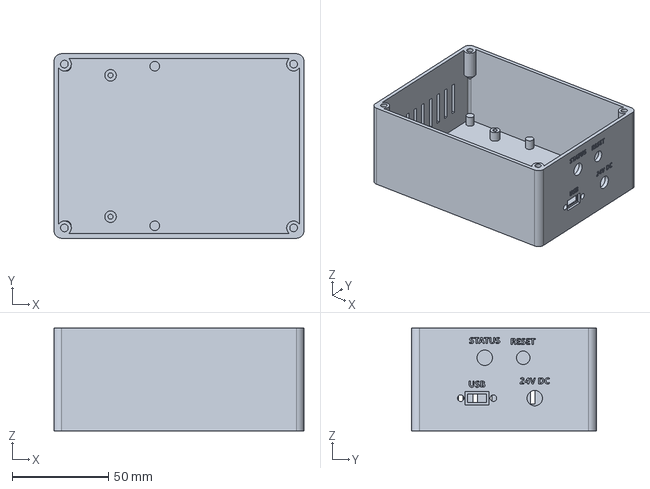
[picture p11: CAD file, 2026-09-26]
enclosure/step/base.step
130.0 x 96.0 x 53.4 mm

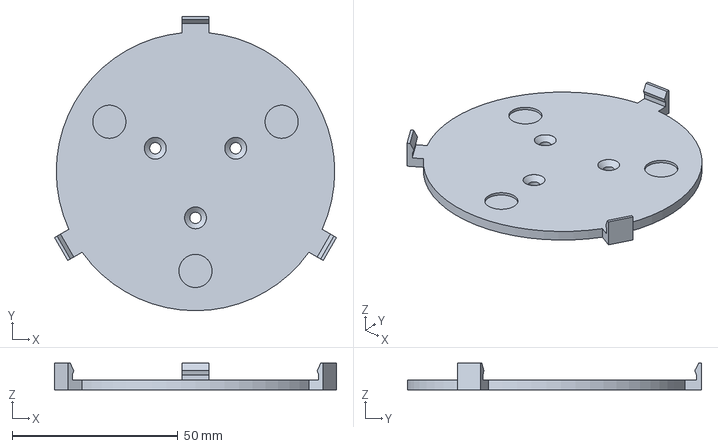
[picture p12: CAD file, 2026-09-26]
enclosure/step/plate.step
85.1 x 88.8 x 8.00 mm

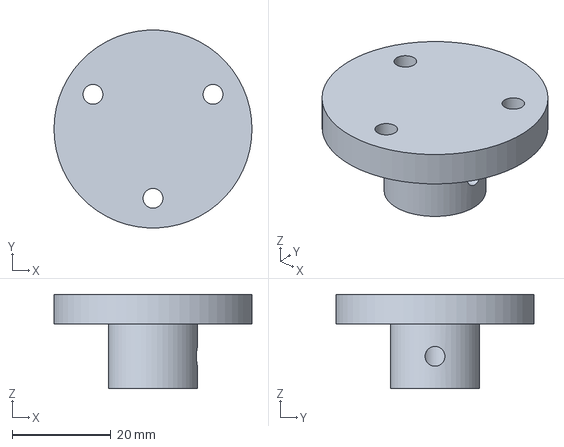
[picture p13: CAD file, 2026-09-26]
enclosure/step/hub.step
40.0 x 39.9 x 19.0 mm

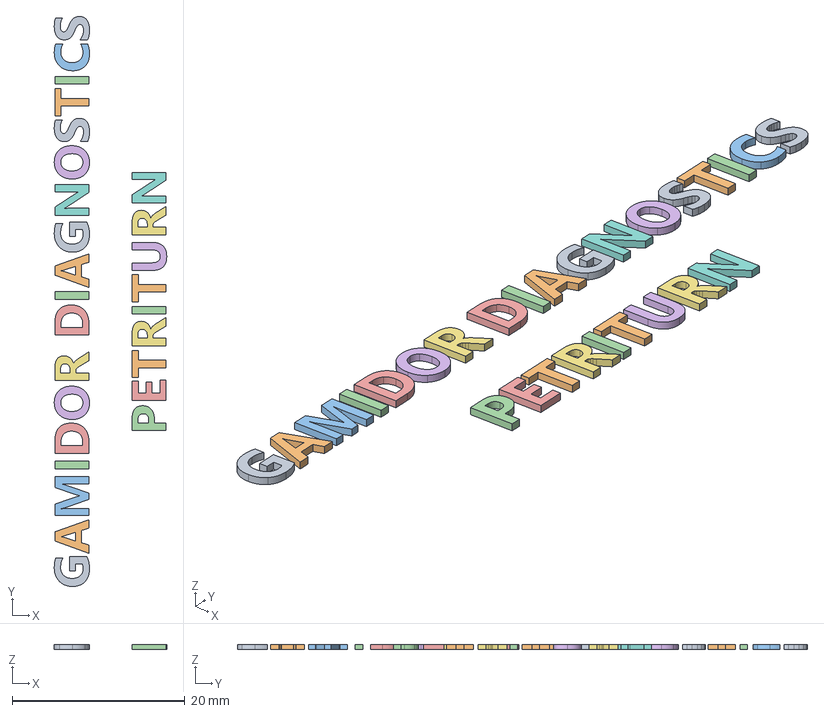
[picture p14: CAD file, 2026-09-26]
enclosure/step/lid_text.step
13.0 x 65.9 x 0.6 mm

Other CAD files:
enclosure/stl/base.stl
enclosure/stl/hub.stl
enclosure/stl/lid.stl
enclosure/stl/lid_text.stl
enclosure/stl/plate.stl

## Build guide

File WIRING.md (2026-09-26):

# חיבורים וחיווט — PetriTurn

המסמך מפרט את כל החיבורים בין הבקר, הדרייבר, המנוע והספק, לפי מספרי רגליים.

הסידור על לוח ההלחמה, עם בדיקה אוטומטית מול המסמך הזה: [perfboard/README.md](perfboard/README.md).

---

## הרכיבים

| רכיב | דגם | הערות |
|---|---|---|
| **בקר** | **Seeed Studio XIAO ESP32-C3** | USB-C מובנה בשבב (אין שבב USB נפרד). מקבל מתח מה-USB |
| **דרייבר** | **TMC2209**, לוח V985 (StepStick) | תקשורת UART בחוט אחד, חיישת זרם `R110` = ‏0.11Ω |
| **מנוע** | LAM M1173040, NEMA17 | ‏1.8° (200 צעדים לסיבוב), ‏0.7A, ‏9.3Ω לסליל, 4 חוטים דו-קוטבי |
| **ספק** | 24V DC, לפחות 1.5A | מתח המנוע בלבד |

---

## מיקום הרגליים

### XIAO ESP32-C3

מבט **מלמעלה** (הרכיבים למעלה, שקע ה-USB-C למעלה):

```
                 USB-C
            ┌─────────────┐
   D0 (1) ──┤             ├── (14) 5V
   D1 (2) ──┤             ├── (13) GND
   D2 (3) ──┤   XIAO      ├── (12) 3V3
   D3 (4) ──┤  ESP32-C3   ├── (11) D10
   D4 (5) ──┤             ├── (10) D9
   D5 (6) ──┤             ├── (9)  D8
   D6 (7) ──┤             ├── (8)  D7
            └─────────────┘
```

- מבט מלמעלה (הרכיבים למעלה), USB-C למעלה. בדיקה: המתכת של שקע ה-USB-C מחוברת ל-`GND`.
- `D0`, `D8`, `D9` — פיני אתחול של השבב. **לא לחבר אליהם דבר.**
- `D6`, `D7` — פנויים (על `D6` השבב מדפיס הודעות אתחול).

| רגל | שם | GPIO | שימוש |
|---|---|---|---|
| 1 | D0 | GPIO2 | **לא בשימוש** (פין אתחול) |
| 2 | D1 | GPIO3 | EN — הפעלת המנוע |
| 3 | D2 | GPIO4 | STEP — צעדים |
| 4 | D3 | GPIO5 | DIR — כיוון |
| 5 | D4 | GPIO6 | UART TX אל הדרייבר (דרך 1kΩ) |
| 6 | D5 | GPIO7 | UART RX מהדרייבר |
| 7 | D6 | GPIO21 | לא בשימוש |
| 8 | D7 | GPIO20 | לא בשימוש |
| 9 | D8 | GPIO8 | **לא בשימוש** (פין אתחול) |
| 10 | D9 | GPIO9 | **לא בשימוש** (פין אתחול, כפתור BOOT) |
| 11 | D10 | GPIO10 | לד STATUS בפאנל (לד עם נגד מובנה) |
| 12 | 3V3 | — | מתח 3.3V ללוגיקה של הדרייבר |
| 13 | GND | — | אדמה משותפת |
| 14 | 5V | — | **לא מחובר** |

### TMC2209 (לוח V985)

מבט מלמעלה, הפוטנציומטר והסימון `EN` למעלה:

```
            VREF DIAG INDEX        (top header - not connected)
            ┌──────────────────┐
  EN    (1) ┤ o   [pot]      o ├ (1) VM
  MS1   (2) ┤ o              o ├ (2) GND
  MS2   (3) ┤ o              o ├ (3) A2
  PDN   (4) ┤ o   TMC2209    o ├ (4) A1
  USART (5) ┤ o              o ├ (5) B1
  CLK   (6) ┤ o              o ├ (6) B2
  STEP  (7) ┤ o              o ├ (7) VDD
  DIR   (8) ┤ o              o ├ (8) GND
            └──────────────────┘
       left side                 right side
```

- **שימו לב:** בצד ימין הסדר הוא `A2` ואחריו `A1` — לא הפוך.
- `PDN` ו-`USART` הם פינים **נפרדים** בלוח הזה, ו**הדרייבר עונה דרך `PDN`** (נבדק על לוח ההלחמה: בלי גשר ל-PDN אין תשובה).
  לכן קו התקשורת מחובר **לשניהם**.
- הטבלה הכתומה של MS1/MS2 על הלוח מתייחסת למצב בלי תקשורת — **לא רלוונטית כאן**.
  המיקרו-צעדים (16) נקבעים בתוכנה.

---

## טבלת חיווט מלאה

### בקר ← דרייבר

| XIAO (רגל) | ← → | TMC2209 (צד, רגל) | רכיב בדרך | הערה |
|---|---|---|---|---|
| **3V3** (12) | → | **VDD** (ימין, 7) | — | מתח לוגיקה לדרייבר |
| **GND** (13) | → | **GND** (ימין, 8) | — | אדמה משותפת — **חובה** |
| **D1** (2) | → | **EN** (שמאל, 1) | — | + נגד 10kΩ מ-EN אל 3.3V (ראו למטה) |
| **D2** (3) | → | **STEP** (שמאל, 7) | — | |
| **D3** (4) | → | **DIR** (שמאל, 8) | — | |
| **D4** (5) | → | **USART** (שמאל, 5) | **נגד 1kΩ** | TX של הבקר |
| **D5** (6) | → | **USART** (שמאל, 5) | — | RX של הבקר, חוט ישיר |
| — | | **MS1** (שמאל, 2) | → GND | כתובת דרייבר = 0 |
| — | | **MS2** (שמאל, 3) | → GND | כתובת דרייבר = 0 |
| `D5` + (`D4` דרך 1kΩ) | | **PDN** (שמאל, 4) | — | **מחובר ל-USART** — הדרייבר מדבר דרך PDN |
| — | | **CLK** (שמאל, 6) | — | **לא מחובר** |
| — | | **VREF, DIAG, INDEX** (עליון) | — | **לא מחוברים** |

### ספק ← דרייבר

| ספק 24V | ← → | TMC2209 (צד, רגל) | הערה |
|---|---|---|---|
| **+24V** | → | **VM** (ימין, 1) | מתח המנוע |
| **−** (0V) | → | **GND** (ימין, 2) | |

### פאנל החיבורים (הדופן הימנית של הקופסה)

| בפאנל | ← → | אל | הערה |
|---|---|---|---|
| **USB-C** (כבל מאריך לפאנל) | → | שקע ה-USB-C של ה-XIAO | דרך מתאם 90° (זווית למעלה) |
| **24V DC** (שקע 5.5×2.1) | → | `VM` / `GND` של הדרייבר | כמו בטבלת הספק למטה |
| **לד STATUS** — רגל ארוכה (+) | → | XIAO `D10` ישירות (**הנגד מולחם על הלד**) | |
| **לד STATUS** — רגל קצרה (−) | → | GND | |
| **כפתור RESET** — רגל 1 | → | **משטח `EN` בגב ה-XIAO** | איפוס אמיתי, כמו כפתור RST |
| **כפתור RESET** — רגל 2 | → | GND | לחצן רגעי, מגע פתוח (NO) |

הלד: **דולק קבוע** = מוכן · **מהבהב לאט** = מסתובב / תוכנית רצה ·
**מהבהב מהר** = הדרייבר לא עונה (בדרך כלל אין 24V) · **כבוי** = אין USB.

### מנוע ← דרייבר

| חוט מנוע | ← → | TMC2209 (צד, רגל) | סליל |
|---|---|---|---|
| **שחור** | → | **A2** (ימין, 3) | A |
| **ירוק** | → | **A1** (ימין, 4) | A |
| **אדום** | → | **B1** (ימין, 5) | B |
| **כחול** | → | **B2** (ימין, 6) | B |

- סליל A = שחור + ירוק. סליל B = אדום + כחול.
- **החלפת שני חוטים בתוך אותו סליל הופכת את כיוון הסיבוב.** אין בזה נזק.
- **ערבוב בין הסלילים** (למשל שחור עם אדום באותו זוג) — המנוע ירעד ולא יסתובב.

---

## נגדים וקבלים

| רכיב | ערך | בין | למה | קוטביות |
|---|---|---|---|---|
| **R1** | **1kΩ** | XIAO `D4` ↔ דרייבר `USART` | הבקר והדרייבר משדרים על אותו חוט; הנגד מגביל זרם כששניהם משדרים יחד | אין |
| **R2** | **10kΩ** | דרייבר `EN` ↔ **3.3V** | שומר את המנוע **כבוי** בזמן עליית הבקר, לפני שהקושחה שולטת בפין | אין |
| **C1** | **100µF / 35V**, אלקטרוליטי | דרייבר `VM` ↔ `GND` (ימין 1–2) | בולע קפיצות מתח מהמנוע ומהחוטים (הדרייבר עומד עד 29V) | **יש!** רגל ארוכה (+) ל-VM, רגל עם פס (−) ל-GND |

- **R2 מתחבר ל-3.3V, לא ל-GND.** מחובר ל-GND — המנוע יידלק מיד עם ה-24V.
- **C1 צמוד לדרייבר** — באותן שורות של הפינים, לא בקצה המטריצה.
- **C1 הפוך יכול להתנפח או להתפוצץ.**

```
            3.3V ─────┬──────────────── VDD (driver)
                      │
                    [R2 10k]
                      │
  XIAO D1 ────────────┴──────────────── EN  (driver)

  XIAO D4 ───[R1 1k]──┐
                      ├──────────────── USART (driver)
  XIAO D5 ────────────┘

  +24V ───────────────┬──────────────── VM  (driver)
                    [C1 100uF +]
  0V   ───────────────┴──────────────── GND (driver, next to VM)
```

---

## בדיקות במולטימטר

### לפני חשמל — הכל מנותק (מצב התנגדות)

| בין | צריך להיות |
|---|---|
| **פס 24V ↔ פס 3.3V** | **נתק (OL)** — הבדיקה החשובה ביותר |
| פס 24V ↔ GND | לא 0 (ערך שעולה לאט — הקבל נטען) |
| 3V3 ↔ GND | לא 0 |
| `EN` ↔ `D1` | ≈0Ω |
| `EN` ↔ 3V3 | ≈10kΩ |
| `STEP` ↔ `D2`, ‏`DIR` ↔ `D3` | ≈0Ω |
| `USART` ↔ `D5` | ≈0Ω |
| `USART` ↔ `D4` | ≈1kΩ |
| `MS1`, `MS2` ↔ GND | ≈0Ω |
| חוטי המנוע: שחור ↔ ירוק | ≈9.3Ω |
| חוטי המנוע: אדום ↔ כחול | ≈9.3Ω |
| חוטי המנוע: שחור ↔ אדום | נתק |

### עם חשמל (מצב מתח ישר)

| בין | צריך להיות |
|---|---|
| `VM` ↔ `GND` (ימין 1–2) | ≈24V |
| `VDD` ↔ `GND` (ימין 7–8) | ≈3.3V |
| `USART` ↔ GND, במנוחה | ≈3.3V |

### בדיקה מהמחשב

`STATUS` (או `petriturn.exe status`) עם 24V מחובר → `DRV=0x21`.
`DIAG` → `A0=12/0x21` = הדרייבר עונה בכתובת 0.

---

## סדר הדלקה וכיבוי

1. **הדלקה:** USB (בקר) קודם → 24V אחר כך.
2. **כיבוי:** לשחרר את הצלחת (`release`) → לכבות 24V → לנתק USB.
3. **לעולם לא לחבר או לנתק את המנוע כשיש 24V** — זה שורף את הדרייבר.
4. להרחיק חוטים משקע ה-USB-C של ה-XIAO — חוט צמוד מונע מהתקע להיכנס עד הסוף.

---

## כיוון הסיבוב

אחרי החיווט, לבדוק פעם אחת:

```
petriturn.exe rotate 0.25 10 cw
```

הצלחת צריכה להסתובב **עם כיוון השעון כשמסתכלים עליה מלמעלה**.

עם החיווט שבמסמך הזה, הקושחה מוגדרת `INVERT_DIR = true` (נבדק על החומרה, 24.09.2026).
אם אחרי שינוי בחיווט הצלחת מסתובבת הפוך — להפוך את `INVERT_DIR` בקושחה ולצרוב מחדש
(או להחליף את השחור והירוק ביניהם, כשה-24V כבוי).

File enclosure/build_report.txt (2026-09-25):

base height 53.4, lid top 57.4, dish bottom 81.4 mm above the bench
footprint 130.0 x 96.0 mm, dish centre x = +13.0 mm
clip grip overlap with the dish: 3.19 mm3 (expected > 0)
base: valid=True solids=1 volume=87.4 cm3
lid: valid=True solids=1 volume=49.0 cm3
hub: valid=True solids=1 volume=10.1 cm3
plate: valid=True solids=1 volume=16.8 cm3
base.stl print size 130.0 x 96.0 x 53.4 mm
lid.stl print size 130.0 x 96.0 x 6.5 mm
lid_text.stl print size 13.0 x 65.9 x 0.6 mm
hub.stl print size 40.0 x 40.0 x 19.0 mm
plate.stl print size 85.1 x 88.8 x 8.0 mm

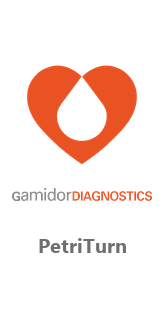
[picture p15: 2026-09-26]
installer/wizard_large_100.bmp

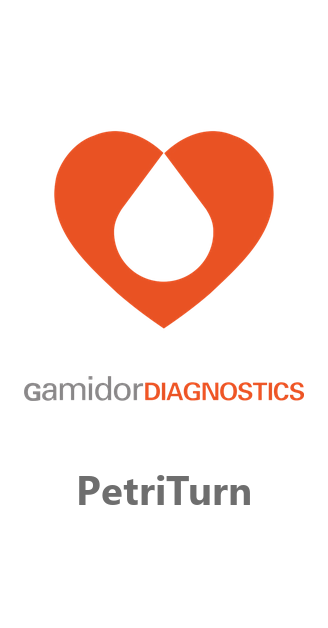
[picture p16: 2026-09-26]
installer/wizard_large_200.bmp

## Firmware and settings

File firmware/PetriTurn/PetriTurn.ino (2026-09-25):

/*
 * PetriTurn — ESP32 + TMC2209 firmware for rotating a petri dish during streaking.
 *
 * Chain:  Robot -> petriturn.exe (Python) -> USB Serial -> ESP32 -> TMC2209 -> NEMA17 -> dish
 *         GUI (petriturn_gui) writes programs into the ESP32 flash; the robot runs them by slot.
 *
 * Libraries (Arduino Library Manager):
 *   - TMCStepper   by teemuatlut
 *   - AccelStepper by Mike McCauley
 * Board: "XIAO_ESP32C3" (Seeed XIAO ESP32-C3, esp32 core by Espressif)
 *   Tools -> USB CDC On Boot: "Enabled"   (the USB-C port is the chip's own USB = Serial)
 *
 * Protocol (USB, 115200, lines end with '\n'). Every command gets exactly one reply line,
 * starting with "OK" or "ERR <reason>".
 *
 *   PING                     -> OK PONG
 *   INFO                     -> OK SLOTS=20 MAX_STEPS=32 MIN_RPM=0.1 MAX_RPM=120 MAX_DEG=36000 MAX_WAIT_MS=600000 ACCEL=1
 *   DIAG                     -> OK A0=<bytes>/0x<ver> A1=... A2=... A3=...   (driver UART wiring test)
 *                               per driver address: bytes received for one read request.
 *                               0 = nothing on the line (XIAO<->USART wiring), 4 = only our own echo
 *                               (driver silent: no 24V / wrong pin), 12 = driver answered (ver 0x21).
 *   STATUS                   -> OK EN=<0|1> BUSY=<0|1> STEP=<i>/<n> POS=<deg> DRV=<0xNN> CUR=<mA> UP=<s> URX=<n>
 *                               UP = seconds since boot; if it drops, the controller was reset.
 *                               URX = times the driver UART froze and was restarted (should stay 0).
 *   EN | DIS                 -> OK            (hold / release the dish)
 *   ZERO                     -> OK            (current position = 0 deg)
 *   ROT <deg> <rpm>          -> OK            (after the motion ends)
 *   RUN <slot>               -> OK            (after the whole program ends)
 *   STOP                     -> OK when idle. While busy it sends NO reply of its own:
 *                               the running ROT/RUN answers "ERR STOPPED" instead.
 *
 *   Program storage (slots 1..20, kept in flash across power cycles):
 *   PLIST                    -> OK 1=Streak A,3=Quadrants        (empty: "OK")
 *   PGET <slot>              -> OK <program>
 *   PSET <slot> <program>    -> OK
 *   PDEL <slot>              -> OK
 *
 * STATUS LED on the panel (D10): steady = ready, slow blink = rotating / program running,
 * fast blink = the driver does not answer (usually no 24V), off = no USB power.
 * RESET button on the panel: wired to the XIAO's EN pad (hardware reset), not a GPIO.
 *
 *   <program> = <name>|<step>|<step>|...
 *   <step>    = ROT <deg> <rpm>      negative deg = other direction (holds the dish on its own)
 *             | WAIT <ms>
 *             | HOLD                 energise the motor: the dish is locked
 *             | RELEASE              de-energise: the dish turns freely by hand
 *   <name>    = 1..24 chars, no '|' ',' '='
 *   Example:  PSET 1 Streak A|HOLD|ROT 360 20|WAIT 1500|ROT -180 10|RELEASE
 */

#include <TMCStepper.h>
#include <AccelStepper.h>
#include <Preferences.h>

// ---------------- Pins: XIAO ESP32-C3 (see Motor_Driver_Design_Notes.md, section 5) ----------------
// Strapping pins D0 (GPIO2), D8 (GPIO8), D9 (GPIO9 = BOOT button) are left unused.
// D6/D7 (GPIO21/20) are left free too: the ROM prints its boot log on GPIO21. D10 = LED.
constexpr uint8_t PIN_EN      = 3;    // D1  LOW = driver active, 10k pull-up keeps it OFF on boot
constexpr uint8_t PIN_STEP    = 4;    // D2
constexpr uint8_t PIN_DIR     = 5;    // D3
constexpr uint8_t PIN_UART_TX = 6;    // D4  via 1k to USART
constexpr uint8_t PIN_UART_RX = 7;    // D5  direct to USART
constexpr uint8_t PIN_LED     = 10;   // D10 status LED on the panel, 330R in series

// ---------------- Motor / driver ----------------
constexpr float    R_SENSE        = 0.11f;   // R110 on the board — verify
constexpr uint8_t  DRIVER_ADDR    = 0b00;    // MS1 = MS2 = GND
constexpr uint16_t RUN_CURRENT_MA = 560;     // 80% of 0.7 A rms
constexpr float    HOLD_MULT      = 0.5f;    // hold current = 50% of run current
constexpr uint16_t MICROSTEPS     = 16;
constexpr long     FULL_STEPS     = 200;
constexpr long     STEPS_PER_REV  = FULL_STEPS * MICROSTEPS;   // 3200
// Positive degrees = clockwise looking down at the dish. true matches the wiring in WIRING.md
// (A2 black, A1 green, B1 red, B2 blue) - checked on the hardware 24.09.2026.
constexpr bool     INVERT_DIR     = true;

// ---------------- Limits ----------------
constexpr float    MIN_RPM      = 0.1f;
constexpr float    MAX_RPM      = 120.0f;
constexpr float    MAX_DEG      = 36000.0f;   // 100 revolutions per step
constexpr uint32_t MAX_WAIT_MS  = 600000;     // 10 minutes per step
constexpr float    ACCEL_REV_S2 = 1.0f;       // gentle ramp so the agar/dish doesn't slip
constexpr int      NUM_SLOTS    = 20;
constexpr int      MAX_STEPS    = 32;
constexpr size_t   MAX_NAME     = 24;
constexpr size_t   CMD_LINE_MAX     = 1024;

// ---------------- Types ----------------
enum StepKind : uint8_t { STEP_ROT, STEP_WAIT, STEP_HOLD, STEP_RELEASE };

struct Step {
  StepKind kind;
  float    deg;   // ROT
  float    rpm;   // ROT
  uint32_t ms;    // WAIT
};

enum Phase { IDLE, MOVING, WAITING };

// ---------------- Globals ----------------
HardwareSerial& DriverSerial = Serial1;   // the C3 has UART0 and UART1 only
TMC2209Stepper driver(&DriverSerial, R_SENSE, DRIVER_ADDR);
AccelStepper   stepper(AccelStepper::DRIVER, PIN_STEP, PIN_DIR);
Preferences    store;

bool     motorEnabled    = false;
uint8_t  driverVersion   = 0;
uint16_t driverCurrentMa = 0;
bool     driverConfigured = false;
uint16_t uartRecoveries   = 0;   // UART to the driver froze and a restart brought it back

constexpr uint32_t DRIVER_CHECK_MS = 2000;   // idle re-check, keeps the LED honest
uint32_t lastDriverCheck = 0;

// program runner
Step     prog[MAX_STEPS];
int      progLen = 0;
int      progIdx = 0;
Phase    phase   = IDLE;
uint32_t waitStart = 0;
uint32_t waitMs    = 0;
bool     stopRequested = false;

char   lineBuf[CMD_LINE_MAX];
size_t lineLen = 0;
bool   lineOverflow = false;   // discard the rest of an over-long line

// ------------------------------------------------------------------------------------
// Helpers

void reply(const char* msg) {
  Serial.println(msg);
}

void replyErr(const char* reason) {
  Serial.print("ERR ");
  Serial.println(reason);
}

void setMotorEnabled(bool on) {
  digitalWrite(PIN_EN, on ? LOW : HIGH);
  motorEnabled = on;
}

float rpmToStepsPerSec(float rpm) {
  return rpm * STEPS_PER_REV / 60.0f;
}

float positionDeg() {
  return stepper.currentPosition() * 360.0f / STEPS_PER_REV;
}

// ------------------------------------------------------------------------------------
// Driver. The TMC2209 logic runs from VM (24V): with only USB/3.3V it does not answer, and
// every time VM comes back it restarts with default settings (current from the potentiometer!).
// So the driver is checked, and re-configured if needed, before anything energises the motor.

void configureDriver() {
  driver.pdn_disable(true);        // PDN pin is used for UART
  driver.I_scale_analog(false);    // ignore the VREF potentiometer, current set in software
  driver.mstep_reg_select(true);   // microsteps from register, not MS1/MS2
  driver.toff(4);
  driver.blank_time(24);
  driver.rms_current(RUN_CURRENT_MA, HOLD_MULT);
  driver.microsteps(MICROSTEPS);
  driver.intpol(true);             // 256 interpolation
  driver.en_spreadCycle(false);    // StealthChop: quiet and smooth at low speed
  driver.pwm_autoscale(true);
  driver.pwm_autograd(true);
  driver.TPOWERDOWN(20);           // ~0.4 s after the last step -> drop to hold current
  driver.GSTAT(0b111);             // clear the "reset" flag, so a later power cycle is detected

  driverCurrentMa = driver.rms_current();
  driverConfigured = true;
}

// true = driver answers and holds our settings. Talks over UART (a few ms): call only when idle.
void startDriverSerial() {
  DriverSerial.begin(115200, SERIAL_8N1, PIN_UART_RX, PIN_UART_TX);
}

bool ensureDriver() {
  driverVersion = driver.version();
  if (driverVersion != 0x21) {
    // The C3's receiver on this line has been seen to stop receiving altogether (not even its
    // own echo) while the motor was held, until the controller was reset. Restarting just the
    // UART brings it back; count it only when that is what fixed it, not when the 24V is off.
    DriverSerial.end();
    startDriverSerial();
    driverVersion = driver.version();
    if (driverVersion == 0x21) uartRecoveries++;
  }
  if (driverVersion != 0x21) {
    driverConfigured = false;
    return false;
  }
  // GSTAT bit0 = the driver restarted (VM came back), bit1 = it shut its outputs down
  // (overtemperature / short, e.g. when VM rises while ENN is already low). Both are latched:
  // the outputs stay off until ENN is toggled, so reconfigure with ENN high, then restore it.
  if (!driverConfigured || (driver.GSTAT() & 0x03)) {
    digitalWrite(PIN_EN, HIGH);
    configureDriver();
    delay(2);
    digitalWrite(PIN_EN, motorEnabled ? LOW : HIGH);
  }
  return true;
}

void toUpper(char* s) {
  for (; *s; ++s) *s = toupper(*s);
}

// Returns true if s was a valid float and writes it to out.
bool parseFloat(const char* s, float& out) {
  if (!s || !*s) return false;
  char* end;
  out = strtof(s, &end);
  return *end == '\0' && isfinite(out);
}

// Returns slot 1..NUM_SLOTS, or 0 if invalid.
int parseSlot(const char* s) {
  float f;
  if (!parseFloat(s, f) || f != floorf(f) || f < 1 || f > NUM_SLOTS) return 0;
  return (int)f;
}

void slotKey(int slot, char* key) {
  snprintf(key, 8, "p%d", slot);
}

// ------------------------------------------------------------------------------------
// Program parsing. All parsers return nullptr on success or an error reason.

const char* parseStep(char* s, Step& st) {
  char* save;
  char* kind  = strtok_r(s, " ", &save);
  char* a     = strtok_r(nullptr, " ", &save);
  char* b     = strtok_r(nullptr, " ", &save);
  char* extra = strtok_r(nullptr, " ", &save);
  if (!kind) return "BAD_STEP";
  toUpper(kind);

  if (!strcmp(kind, "ROT")) {
    float deg, rpm;
    if (!parseFloat(a, deg) || !parseFloat(b, rpm) || extra) return "BAD_ARGS";
    if (fabsf(deg) > MAX_DEG)           return "DEG_RANGE";
    if (rpm < MIN_RPM || rpm > MAX_RPM) return "RPM_RANGE";
    st = {STEP_ROT, deg, rpm, 0};
    return nullptr;
  }
  if (!strcmp(kind, "WAIT")) {
    float ms;
    if (!parseFloat(a, ms) || b) return "BAD_ARGS";
    if (ms < 0 || ms > MAX_WAIT_MS) return "WAIT_RANGE";
    st = {STEP_WAIT, 0, 0, (uint32_t)ms};
    return nullptr;
  }
  if (!strcmp(kind, "HOLD") || !strcmp(kind, "RELEASE")) {
    if (a) return "BAD_ARGS";
    st = {kind[0] == 'H' ? STEP_HOLD : STEP_RELEASE, 0, 0, 0};
    return nullptr;
  }
  return "BAD_STEP";
}

// text = "<name>|<step>|<step>..." (modified in place). name must hold MAX_NAME+1 chars.
const char* parseProgram(char* text, char* name, Step* steps, int& n) {
  char* save;
  char* nm = strtok_r(text, "|", &save);
  if (!nm) return "BAD_NAME";
  size_t len = strlen(nm);
  if (len == 0 || len > MAX_NAME || strpbrk(nm, ",=")) return "BAD_NAME";
  strcpy(name, nm);

  n = 0;
  for (char* s = strtok_r(nullptr, "|", &save); s; s = strtok_r(nullptr, "|", &save)) {
    if (n >= MAX_STEPS) return "TOO_MANY_STEPS";
    const char* err = parseStep(s, steps[n]);
    if (err) return err;
    n++;
  }
  return n ? nullptr : "NO_STEPS";
}

// Canonical text form, so what PGET returns is always parseable.
void formatProgram(const char* name, const Step* steps, int n, char* out, size_t size) {
  size_t pos = snprintf(out, size, "%s", name);
  for (int i = 0; i < n && pos < size; ++i) {
    switch (steps[i].kind) {
      case STEP_ROT:
        pos += snprintf(out + pos, size - pos, "|ROT %g %g", steps[i].deg, steps[i].rpm);
        break;
      case STEP_WAIT:
        pos += snprintf(out + pos, size - pos, "|WAIT %lu", (unsigned long)steps[i].ms);
        break;
      case STEP_HOLD:
        pos += snprintf(out + pos, size - pos, "|HOLD");
        break;
      case STEP_RELEASE:
        pos += snprintf(out + pos, size - pos, "|RELEASE");
        break;
    }
  }
}

// ------------------------------------------------------------------------------------
// Program runner (a single ROT is just a one-step program)

void finishProgram(const char* msg) {
  phase = IDLE;
  progLen = 0;
  stopRequested = false;
  reply(msg);
}

void startStep() {
  while (progIdx < progLen) {
    const Step& st = prog[progIdx];
    if (st.kind == STEP_HOLD || st.kind == STEP_RELEASE) {
      setMotorEnabled(st.kind == STEP_HOLD);
      progIdx++;
      continue;
    }
    if (st.kind == STEP_WAIT) {
      if (st.ms == 0) { progIdx++; continue; }
      waitStart = millis();
      waitMs = st.ms;
      phase = WAITING;
      return;
    }
    long steps = lroundf(st.deg * STEPS_PER_REV / 360.0f);
    if (steps == 0) { progIdx++; continue; }
    if (!motorEnabled) {   // a rotation always runs energised, even after a RELEASE step
      setMotorEnabled(true);
      delay(5);
    }
    stepper.setMaxSpeed(rpmToStepsPerSec(st.rpm));
    stepper.setAcceleration(ACCEL_REV_S2 * STEPS_PER_REV);
    stepper.move(steps);
    phase = MOVING;
    return;
  }
  finishProgram("OK");
}

void startProgram() {
  if (!ensureDriver()) { progLen = 0; replyErr("DRIVER"); return; }
  progIdx = 0;
  stopRequested = false;
  startStep();
}

void serviceProgram(bool moving) {
  if (phase == MOVING && !moving) {
    if (stopRequested) { finishProgram("ERR STOPPED"); return; }
    progIdx++;
    startStep();
  } else if (phase == WAITING && millis() - waitStart >= waitMs) {
    progIdx++;
    startStep();
  }
}

// ------------------------------------------------------------------------------------
// Commands

void cmdStop() {
  if (phase == IDLE)    { reply("OK"); return; }
  if (phase == WAITING) { finishProgram("ERR STOPPED"); return; }
  stopRequested = true;   // decelerate; serviceProgram() sends "ERR STOPPED"
  stepper.stop();
}

void cmdStatus() {
  if (phase == IDLE) ensureDriver();   // live check; skipped while moving to keep steps smooth
  char buf[128];
  snprintf(buf, sizeof(buf), "OK EN=%d BUSY=%d STEP=%d/%d POS=%.2f DRV=0x%02X CUR=%u UP=%lu URX=%u",
           motorEnabled ? 1 : 0, phase != IDLE ? 1 : 0, progLen ? progIdx + 1 : 0, progLen,
           positionDeg(), driverVersion, (unsigned)driverCurrentMa, (unsigned long)(millis() / 1000), (unsigned)uartRecoveries);
  reply(buf);
}

// TMC2209 UART CRC-8 (polynomial 0x07, bits LSB first), from the datasheet.
uint8_t tmcCrc(const uint8_t* data, int len) {
  uint8_t crc = 0;
  for (int i = 0; i < len; ++i) {
    uint8_t b = data[i];
    for (int j = 0; j < 8; ++j) {
      crc = ((crc >> 7) ^ (b & 0x01)) ? (crc << 1) ^ 0x07 : (crc << 1);
      b >>= 1;
    }
  }
  return crc;
}

// Raw read of IOIN (reg 0x06) at every address, bypassing TMCStepper, to see what is on the wire.
void cmdDiag() {
  char buf[128];
  size_t pos = snprintf(buf, sizeof(buf), "OK");
  for (uint8_t addr = 0; addr < 4; ++addr) {
    while (DriverSerial.available()) DriverSerial.read();
    uint8_t req[4] = {0x05, addr, 0x06, 0};
    req[3] = tmcCrc(req, 3);
    DriverSerial.write(req, sizeof(req));
    DriverSerial.flush();

    uint8_t rx[16];
    int n = 0;
    uint32_t t0 = millis();
    while (millis() - t0 < 20 && n < (int)sizeof(rx)) {
      if (DriverSerial.available()) rx[n++] = DriverSerial.read();
    }
    // reply = sync, 0xFF, reg, 4 data bytes (MSB first), crc; the version is the top byte
    uint8_t ver = n >= 12 ? rx[7] : 0;
    pos += snprintf(buf + pos, sizeof(buf) - pos, " A%u=%d/0x%02X", addr, n, ver);
  }
  // What the driver itself reports: pin levels it sees (IOIN bit0 = ENN, bit7 = STEP, bit9 = DIR),
  // latched errors (GSTAT: 1 reset, 2 drv_err, 4 uv_cp) and DRV_STATUS (overtemp / short / open load).
  if (driver.version() == 0x21) {
    pos += snprintf(buf + pos, sizeof(buf) - pos, " IOIN=0x%08lX GSTAT=0x%02X DRV_STATUS=0x%08lX",
                    (unsigned long)driver.IOIN(), (unsigned)driver.GSTAT(),
                    (unsigned long)driver.DRV_STATUS());
  }
  reply(buf);
}

void cmdInfo() {
  char buf[160];
  snprintf(buf, sizeof(buf),
           "OK SLOTS=%d MAX_STEPS=%d MIN_RPM=%g MAX_RPM=%g MAX_DEG=%g MAX_WAIT_MS=%lu ACCEL=%g",
           NUM_SLOTS, MAX_STEPS, MIN_RPM, MAX_RPM, MAX_DEG, (unsigned long)MAX_WAIT_MS, ACCEL_REV_S2);
  reply(buf);
}

void cmdRotate(const char* args) {
  // reuse the step parser, which expects "ROT <deg> <rpm>"
  static char stepText[64];
  snprintf(stepText, sizeof(stepText), "ROT %s", args ? args : "");
  const char* err = parseStep(stepText, prog[0]);
  if (err) { replyErr(err); return; }
  progLen = 1;
  startProgram();
}

void cmdList() {
  static char buf[CMD_LINE_MAX];
  size_t pos = snprintf(buf, sizeof(buf), "OK");
  bool first = true;
  char key[8];
  for (int slot = 1; slot <= NUM_SLOTS; ++slot) {
    slotKey(slot, key);
    if (!store.isKey(key)) continue;
    String text = store.getString(key, "");
    int bar = text.indexOf('|');
    String name = bar >= 0 ? text.substring(0, bar) : text;
    pos += snprintf(buf + pos, sizeof(buf) - pos, "%s%d=%s", first ? " " : ",", slot, name.c_str());
    first = false;
  }
  reply(buf);
}

void cmdGet(char* args) {
  int slot = parseSlot(args);
  if (!slot) { replyErr("BAD_SLOT"); return; }
  char key[8];
  slotKey(slot, key);
  if (!store.isKey(key)) { replyErr("EMPTY_SLOT"); return; }
  String text = store.getString(key, "");
  Serial.print("OK ");
  Serial.println(text);
}

void cmdSet(char* args) {
  if (!args) { replyErr("BAD_SLOT"); return; }
  char* save;
  char* sSlot = strtok_r(args, " ", &save);
  char* body  = strtok_r(nullptr, "", &save);
  int slot = parseSlot(sSlot);
  if (!slot) { replyErr("BAD_SLOT"); return; }
  if (!body) { replyErr("NO_STEPS"); return; }

  static Step steps[MAX_STEPS];
  static char canon[CMD_LINE_MAX];
  char name[MAX_NAME + 1];
  int n;
  const char* err = parseProgram(body, name, steps, n);
  if (err) { replyErr(err); return; }

  formatProgram(name, steps, n, canon, sizeof(canon));
  char key[8];
  slotKey(slot, key);
  if (store.putString(key, canon) == 0) { replyErr("FLASH"); return; }
  reply("OK");
}

void cmdDelete(char* args) {
  int slot = parseSlot(args);
  if (!slot) { replyErr("BAD_SLOT"); return; }
  char key[8];
  slotKey(slot, key);
  if (store.isKey(key)) store.remove(key);
  reply("OK");
}

void cmdRun(char* args) {
  int slot = parseSlot(args);
  if (!slot) { replyErr("BAD_SLOT"); return; }
  char key[8];
  slotKey(slot, key);
  if (!store.isKey(key)) { replyErr("EMPTY_SLOT"); return; }

  static char text[CMD_LINE_MAX];
  store.getString(key, text, sizeof(text));
  char name[MAX_NAME + 1];
  const char* err = parseProgram(text, name, prog, progLen);
  if (err) { progLen = 0; replyErr(err); return; }
  startProgram();
}

void handleLine(char* line) {
  char* save;
  char* cmd  = strtok_r(line, " ", &save);
  char* rest = strtok_r(nullptr, "", &save);
  if (!cmd) return;
  toUpper(cmd);

  if      (!strcmp(cmd, "PING"))   reply("OK PONG");
  else if (!strcmp(cmd, "STATUS")) cmdStatus();
  else if (!strcmp(cmd, "INFO"))   cmdInfo();
  else if (!strcmp(cmd, "DIAG") && phase == IDLE) cmdDiag();
  else if (!strcmp(cmd, "STOP"))   cmdStop();
  else if (phase != IDLE)          replyErr("BUSY");
  else if (!strcmp(cmd, "ROT"))    cmdRotate(rest);
  else if (!strcmp(cmd, "RUN"))    cmdRun(rest);
  else if (!strcmp(cmd, "PLIST"))  cmdList();
  else if (!strcmp(cmd, "PGET"))   cmdGet(rest);
  else if (!strcmp(cmd, "PSET"))   cmdSet(rest);
  else if (!strcmp(cmd, "PDEL"))   cmdDelete(rest);
  else if (!strcmp(cmd, "EN")) {
    if (!ensureDriver()) { replyErr("DRIVER"); return; }
    setMotorEnabled(true);
    reply("OK");
  }
  else if (!strcmp(cmd, "DIS"))    { setMotorEnabled(false); reply("OK"); }
  else if (!strcmp(cmd, "ZERO"))   { stepper.setCurrentPosition(0); reply("OK"); }
  else                             replyErr("UNKNOWN_CMD");
}

void pollSerial() {
  while (Serial.available()) {
    char c = Serial.read();
    if (c == '\r') continue;
    if (c == '\n') {
      lineBuf[lineLen] = '\0';
      if (lineOverflow)  replyErr("LINE_TOO_LONG");
      else if (lineLen)  handleLine(lineBuf);
      lineLen = 0;
      lineOverflow = false;
    } else if (lineLen < sizeof(lineBuf) - 1) {
      lineBuf[lineLen++] = c;
    } else {
      lineOverflow = true;
    }
  }
}

// ------------------------------------------------------------------------------------

void setup() {
  // Keep the motor OFF before anything else (the pull-up already does this in hardware)
  pinMode(PIN_EN, OUTPUT);
  pinMode(PIN_LED, OUTPUT);
  digitalWrite(PIN_LED, LOW);
  digitalWrite(PIN_EN, HIGH);

  Serial.setRxBufferSize(CMD_LINE_MAX);   // a PSET line can be longer than the default 256 bytes
  Serial.begin(115200);
  store.begin("progs", false);

  stepper.setPinsInverted(INVERT_DIR, false, false);
  stepper.setMinPulseWidth(2);

  startDriverSerial();
  driver.begin();
  bool ok = ensureDriver();   // "NOT FOUND" is normal if the 24V is not on yet
  // Informational only; the PC ignores lines that aren't OK/ERR replies.
  Serial.printf("# PetriTurn ready, driver %s (0x%02X)\n", ok ? "OK" : "NOT FOUND (24V off?)", driverVersion);
}
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
void loop() {
  pollSerial();

  // run() returns true while steps remain; call it as often as possible
  bool moving = stepper.run();
  serviceProgram(moving);

  // while idle, check the driver now and then: the LED shows a lost 24V without a host asking,
  // and a driver that restarted gets its settings back before the next command
  if (phase == IDLE && millis() - lastDriverCheck >= DRIVER_CHECK_MS) {
    lastDriverCheck = millis();
    ensureDriver();
  }
  updateLed();
}

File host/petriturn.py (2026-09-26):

"""
petriturn — command-line bridge between the robot and the PetriTurn ESP32.

Usage:
    petriturn run <slot>                    run a stored program, block until it ends
    petriturn rotate <turns> <rpm> cw|ccw   rotate without a program, block until it ends
    petriturn hold                          lock the dish (motor energised)
    petriturn release                       free the dish (turns by hand)
    petriturn stop                          decelerate and stop a motion
    petriturn status                        print driver/motor status
    petriturn list                          list stored programs
    petriturn ping
    petriturn ports                         list the serial ports on this PC

    cw / ccw = clockwise / counter-clockwise, looking down at the dish.
    enable / disable are kept as aliases of hold / release.

Options:
    --port COM6                    serial port for this call only (default: petriturn.ini)

Settings (port, baud rate, timeouts) live in petriturn.ini, and every call is logged (command,
all serial traffic, result, exit code) to logs/<date>_robot_001.log - a new part every day or
every [logs] max_mb. Both in C:\\ProgramData\\PetriTurn once installed.

Exit codes:
    0 = OK
    1 = timeout / no reply / port error / device error / stopped
    2 = bad command, bad arguments or empty slot

Programs are created with petriturn_gui.

Build the exe (from the project root, with the project's .venv):
    .venv\\Scripts\\pyinstaller --onefile --name petriturn host\\petriturn.py
"""

from __future__ import annotations

import argparse
import sys
import time

import serial

from petriturn_link import (BAD_REQUEST_REASONS, ConfigError, PetriTurnError, PetriTurnLink, list_ports,
                          load_config)
from petriturn_log import DEFAULT_MAX_MB, AuditLog

VERSION = "1.1"

EXIT_OK, EXIT_FAIL, EXIT_BAD_CMD = 0, 1, 2


class _Parser(argparse.ArgumentParser):
    log: AuditLog | None = None

    def error(self, message):
        self.print_usage(sys.stderr)
        print(f"ERR {message}", file=sys.stderr)
        if _Parser.log:
            _Parser.log.write("error", f"ERR {message}")
        sys.exit(EXIT_BAD_CMD)


def parse_args():
    p = _Parser(prog="petriturn")
    p.add_argument("--port", help="serial port for this call only (default: petriturn.ini)")
    sub = p.add_subparsers(dest="action", required=True)
    run = sub.add_parser("run")
    run.add_argument("slot", type=int)
    rot = sub.add_parser("rotate")
    rot.add_argument("turns", type=positive_float, help="dish revolutions, e.g. 2 or 0.25")
    rot.add_argument("rpm", type=positive_float, help="speed, revolutions per minute")
    rot.add_argument("direction", type=str.lower, choices=("cw", "ccw"),
                     help="cw = clockwise, ccw = counter-clockwise (looking down at the dish)")
    for name in ("hold", "release", "enable", "disable", "stop", "list", "status", "ping", "ports"):
        sub.add_parser(name)
    return p.parse_args()


def positive_float(text: str) -> float:
    value = float(text)
    if not value > 0:
        raise argparse.ArgumentTypeError(f"must be greater than 0: {text}")
    return value


def execute(link: PetriTurnLink, args) -> str:
    """Runs the action; returns the text to print."""
    if args.action == "run":
        link.run_program(args.slot)
        return "OK"
    if args.action == "rotate":
        # firmware convention: positive degrees = clockwise seen from above
        deg = round(args.turns * 360, 3) * (1 if args.direction == "cw" else -1)
        link.rotate(deg, args.rpm)
        return "OK"
    if args.action == "list":
        programs = link.list_programs()
        return "\n".join(f"{slot}\t{name}" for slot, name in sorted(programs.items())) or "(no programs)"
    if args.action == "status":
        return "OK " + " ".join(f"{k}={v}" for k, v in link.status().items())
    {"hold": link.enable, "enable": link.enable, "release": link.disable, "disable": link.disable,
     "stop": lambda: link.command("STOP"), "ping": link.ping}[args.action]()
    return "OK"


def main(log: AuditLog) -> int:
    args = parse_args()
    if args.action == "ports":
        text = "\n".join(list_ports()) or "(no serial ports)"
        print(text)
        log.write("result", "ports: " + text.replace("\n", ", "))
        return EXIT_OK

    try:
        cfg = load_config()
    except ConfigError as e:
        return fail(log, f"ERR {e}", EXIT_FAIL)
    log.max_bytes = int(cfg.log_max_mb * 1024 * 1024)
    port = args.port or cfg.port
    try:
        link = PetriTurnLink.from_config(cfg, port)
    except serial.SerialException as e:
        return fail(log, f"ERR cannot open {port}: {e}", EXIT_FAIL)
    link.trace = log.write
    log.write("port", f"{port} opened")

    try:
        out = execute(link, args)
        print(out)
        log.write("result", out.replace("\n", " | "))
        return EXIT_OK
    except PetriTurnError as e:
        return fail(log, f"ERR {e.reason}", EXIT_BAD_CMD if e.reason in BAD_REQUEST_REASONS else EXIT_FAIL)
    except TimeoutError as e:
        return fail(log, f"ERR timeout: {e}", EXIT_FAIL)
    except serial.SerialException as e:
        return fail(log, f"ERR port: {e}", EXIT_FAIL)
    except KeyboardInterrupt:
        link.send_stop()
        return fail(log, "ERR interrupted, STOP sent", EXIT_FAIL)
    finally:
        link.close()


def fail(log: AuditLog, message: str, code: int) -> int:
    print(message, file=sys.stderr)
    log.write("error", message)
    return code


def logged_main() -> int:
    log = AuditLog("robot", DEFAULT_MAX_MB)
    _Parser.log = log
    log.session_start(f"petriturn {VERSION} | command: petriturn {' '.join(sys.argv[1:])}")
    t0 = time.monotonic()
    code = EXIT_BAD_CMD
    try:
        code = main(log)
    except SystemExit as e:                 # argparse: bad command line
        code = e.code if isinstance(e.code, int) else EXIT_BAD_CMD
    log.write("exit", f"code {code} after {time.monotonic() - t0:.2f} s")
    if log.error:                           # the call itself still counts; say that it is unlogged
        print(f"WARN {log.error}", file=sys.stderr)
    return code


if __name__ == "__main__":
    sys.exit(logged_main())

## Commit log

2026-09-24 PetriPlatter: petri-dish rotator firmware, robot CLI and control GUI
    - firmware: XIAO ESP32-C3 + TMC2209 over single-wire UART. Programs
    (ROT / WAIT / HOLD / RELEASE steps) stored in flash, 20 slots; driver
    re-checked and re-configured before motion; UART self-recovery (URX
    counter); DIAG command for raw driver diagnostics.
    - host/platter.py: robot command line (run <slot>, rotate, status, ...),
    blocks until motion ends, exit codes 0/1/2.
    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
2026-09-24 Add README and platter.ini settings file
    - README.md (Hebrew): hardware and wiring, first-time setup, platter.ini,
    GUI usage, robot command line with exit codes, serial protocol,
    STATUS fields, error codes, troubleshooting, exe build, safety.
    - host/platter.ini: port, baud rate, timeouts and GUI polling in one file,
    read by both platter.py and platter_gui.py. Created with defaults when
    missing; a successful Connect in the GUI writes the port back (comments
    kept), so the robot uses the same port. Invalid values are reported.
    - platter.py: port comes from platter.ini (--port overrides for one call);
    new "ports" command lists serial ports. PLATTER_PORT env var removed.
    Co-Authored-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
    [platter.py, platter_gui.py, platter_link.py]
2026-09-24 docs: WIRING.md - pin-by-pin wiring of controller, driver, motor and power
    Controller (XIAO ESP32-C3) and driver (TMC2209 V985) pin maps with pin
    numbers, full connection tables, resistor/capacitor placement, multimeter
    checks, power sequence and direction check. Motor colours as wired:
    A2 = black, A1 = green, B1 = red, B2 = blue (README and design notes
    updated to match). WIRING.md is added to the customer package.
2026-09-24 build: include WIRING.md in the customer package
2026-09-24 fix(firmware): INVERT_DIR = true so positive = clockwise with the documented wiring
    Checked on the hardware: with A2 black / A1 green / B1 red / B2 blue the
    dish turned counter-clockwise for positive degrees. WIRING.md notes the
    setting.
    [PetriPlatter.ino]
2026-09-24 feat(gui): demo loop on the manual-control page (Start demo / Stop demo)
    14 rotations cw and ccw from 5 to 120 RPM, about 39 s per lap, each lap
    ending where it started; repeats until Stop demo or STOP. Runs from the
    GUI (no controller slot used); other motion controls are locked while it
    runs and any error ends it. README documents it.
    [platter_gui.py]
2026-09-24 feat(enclosure): 3D-printed SBS-footprint box, parametric FreeCAD script
    - build_enclosure.py: base, lid (+ lettering as a second-colour body),
    shaft hub and dish nest with 3 low snap clips (dish wall stays free
    for the robot gripper). SBS footprint 127.76 x 85.48; motor hangs under
    the lid; perfboard, USB-C window, DC jack, vents. Exports print-ready
    STL and assembled STEP, and checks the parts against models of the
    motor, shaft, board, connectors and dish (report: no collisions).
    - preview_enclosure.py: renders assembled / exploded / print views.
    - enclosure/README.md (Hebrew): parts, Bambu PETG settings, AMS lettering,
    hardware list, what to measure, assembly, dish height for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
    [base.step, base.stl, hub.step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]
2026-09-24 feat(perfboard): component layout for the 30 x 60 controller board
    - perfboard/layout.py: placement (XIAO and TMC2209 on female headers,
    R1, R2, C1, JST-XH motor connector, 24V wires), 11 solder bridges and
    13 wires on the bottom, a netlist check against WIRING.md (every net
    joined, no shorts, PDN/CLK/unused XIAO pins free - verified to catch
    injected mistakes), and top / mirrored bottom drawings.
    - perfboard/README.md (Hebrew): parts and positions, bridge and wire
    tables generated from the checked data, soldering order, multimeter
    checks (verified against the layout).
    - enclosure: XIAO sits at the board edge, USB window 13.5 x 8 so the
    plug overmould fits and the plug seats fu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
    [base.step, base.stl, hub.step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]
2026-09-24 feat(enclosure): run as a FreeCAD macro - shows every part, coloured, in the FreeCAD window
2026-09-24 Controller board moves to the breadboard-style PCB; enclosure follows
    - perfboard/layout.py: layout for the 89 x 52 breadboard-style PCB, cut
    to 32 x 60 (rails off, 22 rows). XIAO and TMC2209 straddle the channel
    like on the test breadboard; the row strips carry most connections,
    11 wires join the rest. The netlist check now models the strips
    (verified to catch 5 injected mistakes).
    - perfboard/README.md (Hebrew): cutting, parts and positions, what runs
    in every row, wire table (generated from the checked data), soldering
    order, multimeter table (verified against the layout).
    - enclosure: board 32 x 60 in the -X/-Y corner; USB-C window and its
    label move to the -Y (long) wall,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
    [base.step, base.stl, hub.step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]
2026-09-24 feat(enclosure): connector panel in the +X end (panel USB-C, 24V, LED, reset)
    - +X end wall: cut-out and 2 screw holes for a panel-mount USB-C
    extension cable, 8 mm DC jack, 8 mm LED holder, 7 mm reset button,
    each labelled above it (USB, 24V DC, STATUS, RESET).
    - The -Y wall USB window is gone; the board moves to y = -20..40 so a
    90 deg USB-C adapter fits in front of the XIAO (modelled, no collision).
    - Collision check models every panel part inside the box.
    [base.step, base.stl, hub.step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]
2026-09-24 Status LED and hardware reset button on the connector panel
    - firmware: STATUS LED on D10 (330R): steady = ready, slow blink =
    rotating / program running, fast blink = driver silent (24V off?).
    While idle the driver is re-checked every 2 s, so the LED shows a lost
    24V without a host asking and a restarted driver is re-configured.
    - perfboard: R3 330R (B4-B8), wires to the panel LED (A8 / A2) and the
    RESET button (B2 = GND; the other side goes to the XIAO's EN pad).
    Netlist check extended (and verified to catch LED/GND mistakes).
    - README (board) and WIRING.md: panel table, reset-wire instructions,
    row table regenerated, two more multimeter checks.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
    [PetriPlatter.ino]
2026-09-24 fix(enclosure): panel USB-C mounts from inside - small opening, 16.5 mm M3 screws, overmould pocket
    The cable's flange sits against the inside of the wall; outside there is a
    10 x 4.5 opening for the plug shell and a 12.4 x 7 pocket, 1.6 deep, so the
    plug's overmould gets in and the plug seats (wall in front is 0.8 mm).
    [base.step, base.stl, hub.step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]
2026-09-25 Wider box for the uncut 89 x 52 board; board layout on the full board
    - enclosure: 130 x 96 (no longer SBS), same height. Motor / dish 13 mm
    towards the connector panel; the full breadboard-style board lies on
    the -X side on 2 M3 standoffs (its own mounting holes, 71.5 apart) and
    4 corner pads. The two posts over the board hang from the lid down to
    just above the parts, with a 45 deg cone (no supports). Vents move to
    the -X end wall; lid lettering in two lines left of the nest.
    No collisions (board, USB adapter zone, panel parts, motor, dish).
    - perfboard: layout on the full 30-row board, 6 rows in - rows 1-6 stay
    free for the 90 deg USB-C adapter. Drawing labels now come from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
    [base.step, base.stl, hub.step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]
2026-09-25 Measured: board mounting holes 73.5 mm apart, panel USB-C screws 17 mm apart
    [base.step, base.stl, hub.step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]
2026-09-25 Panel preview: separate outside/inside views of the USB mount (flange inside, screws from outside)
    [base.step, hub.step, lid.step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]
2026-09-25 Rename the product to PetriTurn (files, exe names, GUI, firmware, docs, lid lettering)
    [base.step, hub.step, lid.step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]
2026-09-25 build.bat: run PyInstaller through python (pyinstaller.exe is blocked by Device Guard)
    [base.step, hub.step, lid.step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]
2026-09-25 Perfboard: XIAO pin sides were mirrored - GND/5V are in column H (measured). Re-routed, check OK
2026-09-25 Perfboard: driver pin sides were mirrored too - logic pins in column D, power in G (measured). Re-routed, check OK
2026-09-25 WIRING: driver drawing is also the back view
2026-09-26 Perfboard: screw terminals for motor, 24V and panel LED/RESET; full per-net connection list in README
2026-09-26 Perfboard: 2.5 mm screw terminals - motor terminal straight on the driver strips, power next to C1
2026-09-26 Perfboard follows the parts as placed (XIAO rows 9-15, driver 19-26); drawings as printed on the board (row 1 top, A left); board turned in the box so the terminals face the motor
    [base.step, hub.step, lid.step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]
2026-09-26 Perfboard: panel LED has its own resistor - R3 removed, W15 from the D10 strip
2026-09-26 WIRING: LED resistor is on the LED
2026-09-26 WIRING: the XIAO and driver drawings were right (top view) - remove the wrong back-view notes
2026-09-26 Driver talks on PDN (tested on the board): PDN bridged to the USART line (W16)
2026-09-26 Audit logs: robot CLI and GUI log every action to logs/<date>_<robot|gui>_NNN.log, new part per day or max_mb (5 MB), never deleted; write failures reported
    [petriturn.py, petriturn_gui.py, petriturn_link.py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]
2026-09-26 Windows installer (Inno Setup): one Setup exe with Gamidor branding, choice of folder, desktop shortcut, Start menu, uninstall. Settings and logs move to C:\ProgramData\PetriTurn (writable, kept on u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
    [petriturn.py, petriturn_gui.py, petriturn_link.py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]
